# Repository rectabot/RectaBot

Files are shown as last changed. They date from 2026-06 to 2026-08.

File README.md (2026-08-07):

# RectaBot — 5-Axis CNC Controller

Open-source 5-axis CNC controller based on the Raspberry Pi RP2350B microcontroller running grblHAL firmware. Designed for hobby and workshop applications.

🌐 **[rectabot.org](https://rectabot.org)** — product, documentation and firmware configurator.

_RectaBot is the first piece of an open CNC ecosystem we're actively building. New parts are shared here as they're finished and verified — no roadmaps, no dates, just working hardware and software._

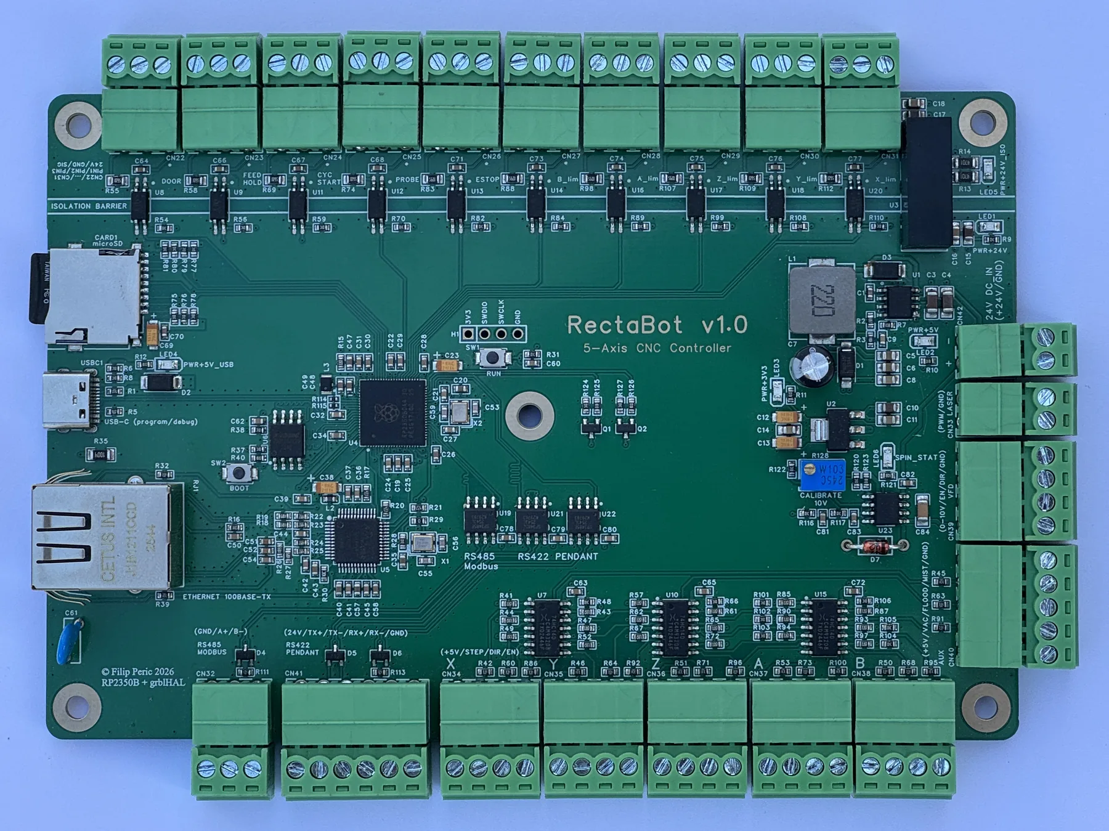
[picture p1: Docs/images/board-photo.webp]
RectaBot v1.0 — assembled board


---

## 📊 Project Status

| | |
|---|---|
| **Current version** | v1.0 |
| **Status** | ✅ v1.0 — running a machine: homing, probing, Modbus spindle, Ethernet, SD. One interface is hardware only — the RS-422 pendant header, which the firmware does not use |
| **First production batch** | 5 boards (JLCPCB Economic PCBA + ENIG finish) |
| **Firmware** | grblHAL fork for RP2350B |
| **Software** | [RectaControl](https://github.com/rectabot/RectaControl) — desktop sender built for this board |
| **Form factor** | 150 × 100 mm, 4-layer PCB, 1.6mm |

---

## 🎯 What is RectaBot?

A 5-axis CNC controller with optical input isolation, integrated Ethernet, and a VFD interface.

### Key features

- 🧩 **Single-board, fully integrated** — no add-on driver boards, breakout modules, or level-shifter add-ons to wire up. Every active part is soldered down (only the field-wiring terminals plug in), so vibration can't work a module loose over time; high-speed step/dir and comms lines are laid out for EMI immunity. Stepper drivers stay external — this board commands DM556-class drivers rather than replacing them — and coolant needs 2–3 relays on `CN40` — an optocoupler-input module or a solid-state relay, both wired and run ([which ones](Docs/Assembly/Quick_Start_Guide.md#which-relay-to-buy))
- ⚙️ **5-axis stepper control** (X, Y, Z, A, B) — PIO-based step generation up to **300kHz per axis**
- 🔌 **Spindle 0-10V interface** with overvoltage protection — compatible with Huanyang/Lapond/Delta/Hitachi VFDs
- 🛡️ **Optically isolated inputs** — all 10 field inputs through LTV-217-B-G optocouplers on a dedicated 24V_ISO rail (input side only)
- 🌐 **On-board Ethernet 10/100 Mbps** — a **discrete W5500** PHY laid out to WIZnet's reference design and their engineers' recommendations (not a plug-on module), with J1B1211CCD integrated magnetics + Bob Smith termination and controlled 100Ω differential pairs
- 💾 **MicroSD slot** for G-code files and configuration
- 🔋 **24V DC power input** (buck-regulated to 5V) — **ORing Schottky diodes** let the 24V supply and USB-C stay connected **at the same time** and hand off the 5V rail automatically; **no VBUS/5V select jumpers** to flip by hand (also blocks USB-C back-feed)
- 📡 **RS-485 Modbus + RS-422 Pendant** interfaces
- 🚦 **10 isolated inputs** + **3 auxiliary 5 V outputs** (Mist M7 / Flood M8 / Vac M62) — 330 Ω series, 25 mA per pin; drives relay modules and solid-state relays alike

**Detailed specification:** [Docs/Reference/Product_Specification_v1.0.md](Docs/Reference/Product_Specification_v1.0.md)

---

## 📂 Repository structure

```
RectaBot/
├── Docs/                                # 📚 All documentation (read first!)
│   ├── Assembly/                        # Build & first power-on
│   │   ├── Quick_Start_Guide.md         # From unboxing to first motor (2-3h)
│   │   ├── First_Power_On_Procedure.md  # Safe first power-on with a multimeter
│   │   └── Hand_Solder_Components.md     # 28 TH components for hand-soldering
│   ├── Reference/                       # Electrical & design reference
│   │   ├── Product_Specification_v1.0.md # Complete datasheet/spec
│   │   ├── Pinout.md                    # RP2350B pinmap (GP0-GP47)
│   │   ├── Schematic_References.md       # Reference schematics for all ICs
│   │   ├── Hardware_Design_Guidelines.md # PCB layout guidelines
│   │   ├── VFD_Wiring_Guide.md          # VFD connection guide (analog 0-10V)
│   │   └── VFD_Modbus_Setup.md          # VFD spindle control over RS-485/Modbus
│   ├── Manufacturing/                   # Send-to-fab production data
│   │   ├── BOM_v1.0_final.csv           # Bill of Materials (~80 components)
│   │   ├── CPL_RectaBot_V1.0.csv        # Component Placement List for JLCPCB
│   │   ├── LCSC_Additional_Order.csv    # TH parts for a separate LCSC order
│   │   └── Gerber_RectaBot_1.0/         # Production-ready Gerber files
│   └── Brand_Assets/                    # Logo files (SVG) — brand reserved, not open-licensed
├── website/                             # rectabot.org — landing page, deployed by Actions
│   └── configurator/                    # Firmware picker: machine layout → the matching .uf2
│
└── (Submodules live in separate repos — see below)
```

## 🔗 Related repositories

RectaBot is split across separate GitHub repos for better modularity:

| Repo | Contents |
|---|---|
| **[rectabot/RectaBot](https://github.com/rectabot/RectaBot)** (this one) | Hardware design (Gerber), docs, BOM, brand assets, configurator tool |
| **[rectabot/RectaBot-firmware](https://github.com/rectabot/RectaBot-firmware)** | grblHAL fork with RectaBot board map + pre-built UF2 |
| **[rectabot/RectaControl](https://github.com/rectabot/RectaControl)** | Desktop sender (Electron) — settings, probing, 3D toolpath, firmware flashing |

**Clone everything at once:**
```powershell
git clone https://github.com/rectabot/RectaBot.git
git clone https://github.com/rectabot/RectaBot-firmware.git
git clone https://github.com/rectabot/RectaControl.git
```

---

## 🔧 Hardware

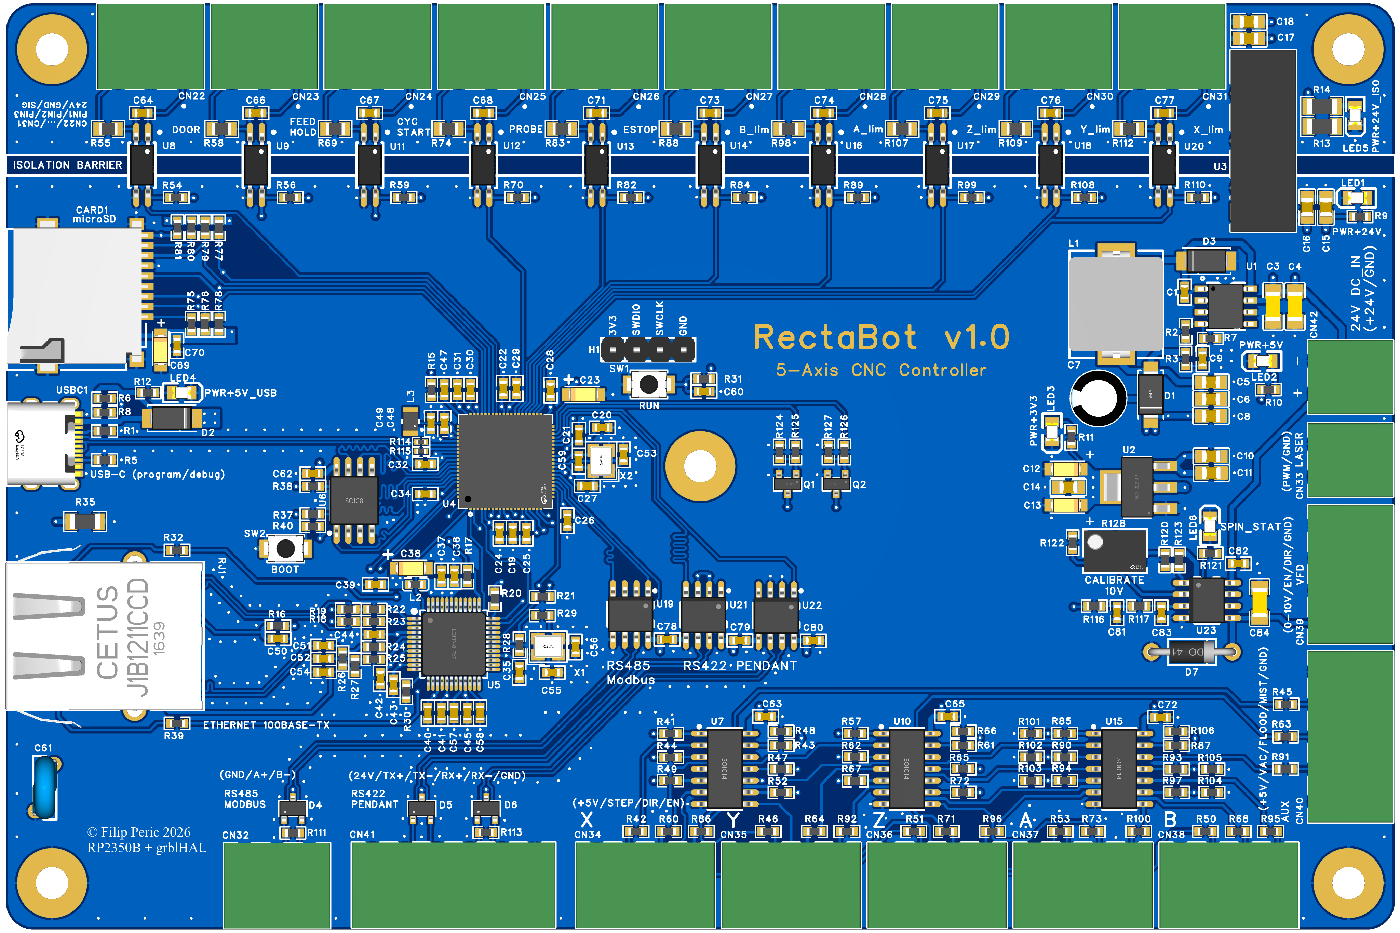
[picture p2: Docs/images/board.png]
RectaBot v1.0 — board layout with silkscreen labels


### Core components

| Component | Role |
|---|---|
| **Raspberry Pi RP2350B** (QFN-80) | Dual ARM Cortex-M33 @ 150MHz, 48 GPIO, 12 PIO state machines |
| **WIZnet W5500** | Hardware TCP/IP stack, 10/100 Ethernet |
| **74HC14D ×3** | Schmitt-trigger inverters for 3.3V→5V level shift (all step/dir/en signals) |
| **LTV-217-B-G ×10** | Optocouplers for all input signals (limit switches, ESTOP, probe, controls) |
| **LM358DR2G** | Op-amp for PWM→0-10V spindle interface |
| **2N7002 ×2** | Open-drain MOSFETs for VFD EN/DIR signals |
| **SP3485EN-L/TR ×3** | 3.3V native RS-485/RS-422 transceivers (1 Modbus + 2 Pendant) |
| **B2424S-2WR3** | Isolated 24V→24V DC/DC for opto LED supply |

### Power Tree

```
24V DC IN ──┬──► TPS5430 buck ──► +5V (3A)
            │                                 │
            ├──► B2424S-2WR3 isolation ──► +24V_ISO (opto LEDs)
            │
            └──► LM358 (op-amp supply, 24V rail-to-rail)

+5V ──► AMS1117-3.3 LDO ──► +3.3V (MCU, W5500, SP3485)
```

### System Block Diagram

```
                       ┌─────────────────────────────────────┐
                       │     RectaBot v1.0 — RP2350B MCU     │
                       │   (Dual Cortex-M33 @ 150MHz)        │
                       └─────────────────────────────────────┘
                                       │
       ┌───────────────────────┬───────┴───────┬───────────────────────┐
       │                       │               │                       │
       ▼                       ▼               ▼                       ▼
┌──────────────┐        ┌──────────────┐ ┌──────────────┐       ┌──────────────┐
│  MOTION      │        │  SPINDLE     │ │  AUX (RELAY) │       │  I/O & COMM  │
│              │        │              │ │              │       │              │
│ PIO step gen │        │ PWM @ 25kHz  │ │ GP0-2 →      │       │ SPI0 W5500   │
│ GP8-22 →     │        │ GP27 →       │ │ 74HC14D      │       │ UART1 RS485  │
│ 74HC14D ×3   │        │ LM358 op-amp │ │ Mist/Flood/  │       │ UART0 RS422  │
│ (Schmitt inv)│        │ + 2N7002 ×2  │ │ Vacuum       │       │ SPI1 microSD │
└──────┬───────┘        └──────┬───────┘ └──────┬───────┘       └──────┬───────┘
       │                       │                │                      │
       ▼                       ▼                ▼                      ▼
┌──────────────┐        ┌──────────────┐ ┌──────────────┐       ┌──────────────┐
│ CN34-CN38    │        │ CN39 (VFD)   │ │ CN40 (AUX)   │       │ RJ45 + USB-C │
│ 5× Stepper   │        │ 0-10V analog │ │ Mist/Flood/  │       │ + CN32 RS485 │
│ STEP/DIR/EN  │        │ EN/DIR open- │ │ Vacuum +     │       │ + CN41 RS422 │
│ (5V CMOS)    │        │ drain MOSFET │ │ 5V/VAC/GND   │       │ + microSD    │
└──────────────┘        └──────────────┘ └──────────────┘       └──────────────┘

     ─ ─ ─ ─ ─ ─ ─ ─ ─ ─ ─ INPUT-SIDE ISOLATION (10× OPTO) ─ ─ ─ ─ ─ ─ ─ ─ ─ ─ ─

                              ┌─────────────────────┐
                              │  10× ISOLATED       │
                              │  INPUTS             │
                              │                     │
                              │ LTV-217-B-G opto    │
                              │ + 24V_ISO domain    │
                              │ (B2424S-2WR3 DC/DC) │
                              │                     │
                              │ Limits, ESTOP,      │
                              │ Probe, Controls     │
                              │                     │
                              │ → CN22-CN31         │
                              └─────────────────────┘

Note: v1 isolates the input side only.
```

---

## 🚀 Quick Start

> **📦 Status:** The first batch of five v1.0 boards has been assembled, and a board has been driving a machine since: homing and hard limits, probing cycles, a Modbus VFD spindle, Ethernet, the SD card and the coolant outputs. Everything documented below is verified on hardware, with one exception — nothing has yet been connected to the **RS-422 pendant header (CN41)**. Its transceivers are populated and its pins are documented, but the link has never carried traffic, so treat that one interface as untested. Follow the assembly and wiring guides below.

**Main guides:**
- **[Quick_Start_Guide.md](Docs/Assembly/Quick_Start_Guide.md)** — Complete walkthrough from unboxing to first motor (estimated: 2-3h)
- **[First_Power_On_Procedure.md](Docs/Assembly/First_Power_On_Procedure.md)** — Safety procedure for the first power-on with a multimeter

**Main steps (summary):**
1. Visual inspection of the board (10 min)
2. Hand-soldering 28 TH components ([list](Docs/Assembly/Hand_Solder_Components.md), 60-90 min)
3. Pre-Power-On continuity tests (15 min)
4. First Power-On + LED + voltage verification (10 min)
5. Firmware flash via BOOTSEL+USB (15 min) — [the configurator](https://rectabot.org/configurator/) names the `.uf2` your motor layout needs
6. grblHAL configuration (`$$` parameters for RectaBot, 20 min) — RectaControl's Settings panel, with a steps/mm calculator
7. First axis test with a DM556 driver (10 min)
8. VFD wiring — [analog 0-10V](Docs/Reference/VFD_Wiring_Guide.md) or [RS-485/Modbus](Docs/Reference/VFD_Modbus_Setup.md)

---

## 🤝 Acknowledgments

- **[grblHAL](https://github.com/grblHAL)** community — for the incredible open-source firmware
- **Raspberry Pi Foundation** — for the RP2350 chip and accessible pricing
- **JLCPCB & LCSC** — for accessible prototype manufacturing
- **EasyEDA** — for the CAD tool that made this project possible for a solo developer

---

## 📜 License

- **Code, documentation:** MIT (see [LICENSE](LICENSE))
- **Hardware design files** (Gerber, BOM, CPL): CERN-OHL-S v2 (see [LICENSE.hardware](LICENSE.hardware))
- **Brand assets** (the name "RectaBot" + logo SVGs): **reserved — all rights reserved**, not open-licensed (see [Docs/Brand_Assets/README.md](Docs/Brand_Assets/README.md))
- **grblHAL firmware fork:** GPL-3.0 (inherits from upstream, in the separate [RectaBot-firmware](https://github.com/rectabot/RectaBot-firmware) repo)
- **RectaControl sender:** GPL-3.0 (separate [RectaControl](https://github.com/rectabot/RectaControl) repo)

---

## 📬 Contact

**Project lead:** Filip Perić
**Website:** [rectabot.org](https://rectabot.org)
**Email:** hello@rectabot.org
**Location:** Serbia

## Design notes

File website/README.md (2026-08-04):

# rectabot.org — RectaBot website

Static landing page + grblHAL firmware configurator for RectaBot. Part of the
`rectabot/RectaBot` repo; deployed to GitHub Pages (custom domain **rectabot.org**)
from this `website/` folder via `.github/workflows/deploy-pages.yml`.

- `index.html` — landing page (zero build; Tailwind + fonts via CDN)
- `configurator/` — firmware selector; the only copy. Its `VARIANTS` map and the
  firmware repo's `variants/` folders share the same keys, so a new build means
  adding it in both places
- `board-photo.webp` / `board-photo-full.webp` — board photo (thumbnail + lightbox)
- `rectacontrol.png` — sender screenshot; copied from the RectaControl repo's
  `docs/images/rectacontrol.png`, re-copy it when the UI changes
- `Brand_Assets/favicon.svg`, `favicon.svg` — browser tab icon (identical files)
- `apple-touch-icon.png` — 180×180, for iOS home screens, which ignore SVG icons.
  Resized from the RectaControl app icon (`rectacontrol/build/icon.png`), so the
  two stay the same picture; regenerate from there if the brand mark changes
- `CNAME` — custom domain (rectabot.org)

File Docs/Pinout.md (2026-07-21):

# RP2350B Pinmap (RectaBot v1.0)

The RP2350B (QFN-80) has 48 GPIO pins (GP0-GP47).

**Level shift 3.3V → 5V:** Stepper signals (STEP/DIR/EN) and coolant outputs (VAC/FLOOD/MIST) pass through the **74HC14D** (Schmitt-trigger HEX inverter, Basic part on JLCPCB). Three 74HC14D chips (U7, U10, U15) cover 18 signals.

**The 74HC14D inverts the signal, but in Common Anode mode this is already accounted for** — no firmware STEP invert is needed. Validated on bench (TB6600 + NEMA17, smooth both directions, no missed steps up to F2000):
- `$2=0` — STEP_INVERT_MASK. With `$2=0` the 74HC14D output idles HIGH (OPT− high → opto OFF) and each step pulse briefly pulls OPT− low (opto ON) — correct for Common Anode. Setting `$2`≠0 would hold the input opto continuously ON at idle and likely cause missed steps at speed.
- `$3=0` — DIRECTION_INVERT_MASK baseline. Set per-axis on the actual machine so X+/Y+/Z+ move in the correct direction.
- `$4` — STEPPER_ENABLE_INVERT_MASK: **not yet validated** (ENA left unconnected during bench test, driver always enabled). Verify once ENA is wired to the drivers.
- Coolant invert via driver configuration

Stepper drivers operate in **Common Anode** mode: +5V on OPT+, the 74HC14D pulls OPT− to GND. Validated with TB6600; verified-under-load values (and any driver-specific differences, e.g. DM-series) to be confirmed when machining.

**Input galvanic isolation:** 10 isolated inputs via **LTV-217-B-G** optocouplers (U8-U20), powered from **+24V_ISO** (B2424S-2WR3 isolated DC/DC). GND_ISO is separated from GND by a 2mm copper void barrier.

**Input wiring (each connector: `24V · GND · SIG`):** the inputs are **sinking (active LOW)** — same convention as the VFD outputs.
- **Mechanical switch** (limit / E-stop, NO contact): wire between **GND** and **SIG**. The 24V pin is not needed.
- **Inductive sensor — NPN (sinking), recommended** (e.g. LJ12A3): use all three pins — **24V** (power) + **GND** + **SIG**. The sensor pulls SIG to GND when triggered.
- **PNP (sourcing) sensors are not directly compatible** (they drive SIG to 24V) — use an external relay module, as with PNP VFDs.

See the [hardware configurator](configurator/index.html) (Limit input type: NPN vs Mechanical) for the matching grblHAL `$` settings.

| Function | RP2350 Pin | Notes |
| :--- | :--- | :--- |
| **Auxiliary outputs** | | Through 74HC14D FREE channels → SSR |
| VAC | `GP0` | Through 74HC14D (inverted) → SSR, grblHAL M62/M63 |
| FLOOD | `GP1` | Through 74HC14D (inverted) → SSR, grblHAL M8/M9 |
| MIST | `GP2` | Through 74HC14D (inverted) → SSR, grblHAL M7/M9 |
| SD Card Detect | `GP3` | MicroSD socket CD switch (active LOW when card inserted) |
| **W5500 Ethernet (SPI0)** | | |
| MISO | `GP4` | SPI0 RX |
| SCSn | `GP5` | SPI0 CS |
| SCLK | `GP6` | SPI0 SCK |
| MOSI | `GP7` | SPI0 TX |
| **X axis** | | Through 74HC14D |
| STEP_X → STEP_X_5V | `GP8` | 74HC14D input/output |
| DIR_X → DIR_X_5V | `GP13` | 74HC14D input/output |
| EN_X → EN_X_5V | `GP18` | 74HC14D input/output |
| **Y axis** | | Through 74HC14D |
| STEP_Y → STEP_Y_5V | `GP9` | 74HC14D input/output |
| DIR_Y → DIR_Y_5V | `GP14` | 74HC14D input/output |
| EN_Y → EN_Y_5V | `GP19` | 74HC14D input/output |
| **Z axis** | | Through 74HC14D |
| STEP_Z → STEP_Z_5V | `GP10` | 74HC14D input/output |
| DIR_Z → DIR_Z_5V | `GP15` | 74HC14D input/output |
| EN_Z → EN_Z_5V | `GP20` | 74HC14D input/output |
| **A axis** | | Through 74HC14D |
| STEP_A → STEP_A_5V | `GP11` | 74HC14D input/output |
| DIR_A → DIR_A_5V | `GP16` | 74HC14D input/output |
| EN_A → EN_A_5V | `GP21` | 74HC14D input/output |
| **B axis (Y2 tandem)** | | Through 74HC14D |
| STEP_B → STEP_B_5V | `GP12` | 74HC14D input/output |
| DIR_B → DIR_B_5V | `GP17` | 74HC14D input/output |
| EN_B → EN_B_5V | `GP22` | 74HC14D input/output |
| **W5500 Ethernet** | | |
| W5500_INT (INTn) | `GP23` | Interrupt |
| **RS485 Modbus** | UART1 | MAX485 or external module |
| RS485 TX | `GP24` | UART1 TX → MAX485 DI |
| RS485 RX | `GP25` | UART1 RX ← MAX485 RO |
| RS485 DE/RE | `GP26` | Direction control |
| **Spindle / Laser** | | |
| Spindle PWM / Laser PWM | `GP27` | PWM for VFD and laser diode module (3.3V TTL, shared with CN39 + CN33). For VFD it goes through the LM358 0-10V converter; for laser, directly to CN33. |
| RS422 TX (Pendant) | `GP28` | UART0 TX → SP3485 Chip1 (TX hardwired) |
| RS422 RX (Pendant) | `GP29` | UART0 RX ← SP3485 Chip2 (RX hardwired) |
| Spindle Enable (VFD_EN) | `GP30` | Enable VFD → 2N7002 open-drain Q1 → CN39 pin 2 (VFD_EN, active LOW open-drain) |
| Spindle Dir (VFD_DIR) | `GP31` | Direction VFD → 2N7002 open-drain Q2 → CN39 pin 3 (VFD_DIR, active LOW open-drain) |
| W5500_RST (RSTn) | `GP32` | W5500 reset, 4.7kΩ pull-up |
| **Limits / Control inputs** | | Via LTV-217-B-G opto, 24V_ISO |
| X_MIN | `GP33` | X-axis limit switch |
| Y_MIN | `GP34` | Y-axis limit switch |
| Z_MAX | `GP35` | Z-axis limit switch (homing up) |
| A_MIN | `GP36` | A-axis limit switch |
| B_MIN | `GP37` | B-axis limit switch (Y2 auto-square) |
| ESTOP | `GP38` | Emergency Stop → grblHAL alarm |
| PROBE | `GP39` | Tool length probe |
| CYCLE_START | `GP40` | Cycle start |
| FEED_HOLD | `GP41` | Pause |
| DOOR | `GP42` | Safety door input (grblHAL `SAFETY_DOOR`): opening the door holds the machine until closed. Neutral default (no forced invert) — set `$14` DOOR bit to match the switch (NO/NC). |
| **SD card (SPI1)** | | |
| SD MOSI | `GP43` | SPI1 TX |
| SD MISO | `GP44` | SPI1 RX |
| SD CS | `GP45` | SPI1 CSN |
| SD CLK | `GP46` | SPI1 SCK |
| VBUS_DET | `GP47` | USB VBUS detect, 10kΩ/10kΩ divider (R6/R8) → 2.5V (above VIH=2.15V) |

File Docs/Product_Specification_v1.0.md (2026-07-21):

# RectaBot v1.0 — Product Specification

**Industrial-grade 5-axis CNC controller with integrated network, USB, isolated I/O, and spindle 0-10V interface.**

---

## 📑 Table of Contents

- [Product Overview](#-product-overview)
- [Key Features](#-key-features)
  - [Motion Control](#motion-control)
  - [Spindle Control](#spindle-control-new-in-v10)
  - [Isolated I/O](#isolated-io)
  - [Connectivity](#connectivity)
  - [Power Distribution](#power-distribution)
  - [Safety & EMI](#safety--emi)
- [Connector Pinout](#-connector-pinout)
  - [Power & USB](#power--usb)
  - [Stepper Motors](#stepper-motors-x-y-z-a-b)
  - [Spindle / Laser](#spindle--laser)
  - [Isolated Inputs](#isolated-inputs-24v_iso-domain)
  - [Auxiliary / Communication](#auxiliary--communication)
- [Electrical Specifications](#-electrical-specifications)
  - [Power](#power)
  - [Stepper Outputs](#stepper-outputs-per-axis)
  - [Spindle 0-10V Output](#spindle-0-10v-output)
  - [Spindle EN/DIR Outputs](#spindle-endir-outputs)
  - [Isolated Inputs](#isolated-inputs)
  - [Communication](#communication)
- [Compliance & Reliability](#-compliance--reliability)
- [Compatibility](#-compatibility)
  - [Stepper Drivers](#stepper-drivers)
  - [VFD Compatibility](#vfd-variable-frequency-drives)
  - [Laser Modules](#laser-modules)
  - [CNC Machines](#cnc-machines)
- [Onboard Components Summary](#-onboard-components-summary)
- [Mechanical](#-mechanical)
- [Firmware](#-firmware)
- [In the Box](#-in-the-box)
- [Documentation](#-documentation)
- [Support](#-support)
- [Legal](#-legal)
- [Revision History](#-revision-history)

---

## 📦 Product Overview

RectaBot is a professional CNC mill controller designed for hobby-pro and small workshop applications. Built around the powerful **Raspberry Pi RP2350B** microcontroller running open-source **grblHAL** firmware, it combines industrial-grade isolation, multi-axis stepper control, and modern connectivity in a single 150×100mm PCB.

| Property | Value |
|---|---|
| **Model** | RectaBot v1.0 |
| **Form factor** | 150×100mm 4-layer PCB |
| **MCU** | Raspberry Pi RP2350B (QFN-80, dual ARM Cortex-M33 @ 150MHz) |
| **Firmware** | grblHAL (open-source) |
| **Power input** | 24V DC, 2A max |
| **Operating temperature** | -10°C to +60°C |
| **PCB layers** | 4 (top signal, GND plane, power plane, bottom signal) |
| **Input isolation** | Optical isolation on all 10 field inputs (LTV-217-B-G, 5kV rated, 24V_ISO domain). Outputs share MCU ground in v1. |

---

## 🎯 Key Features

### Motion Control
- ✅ **5-axis stepper control** (X, Y, Z, A, B) via PIO-based step generation
- ✅ **Common Anode** drive topology for DM556 / TB6600 / DM860 driver compatibility
- ✅ **5V logic-level** STEP/DIR/EN signals (via 74HC14D Schmitt trigger buffer)
- ✅ Hardware-accelerated step pulses up to **300kHz per axis**
- ✅ Y-axis auto-squaring (B-axis as ganged Y2)

### Spindle Control (NEW in v1.0)
- ✅ **0-10V analog speed output** for VFD compatibility (LM358 op-amp with trim calibration)
- ✅ **Open-drain Enable & Direction signals** (2N7002 MOSFET, 60V tolerant)
- ✅ **Overvoltage protection** (12V Zener clamp on 0-10V output)
- ✅ Compatible with **Huanyang, Lapond, Delta, ATO, Hitachi** VFDs out-of-the-box
- ✅ PWM range: 0-25kHz, supports laser modulation on shared output
- ✅ Visual brightness LED indicator follows actual VFD output

### Isolated I/O
- ✅ **10 optically isolated inputs** (24V_ISO domain, LTV-217 optocouplers, 5kV component rating)
  - 5× limit switches (X_MIN, Y_MIN, Z_MAX, A_MIN, B_MIN)
  - E-Stop, Probe, Cycle Start, Feed Hold, Door safety
- ✅ **3 SSR-compatible outputs** (Mist M7, Flood M8, Vacuum M62/M63)
- ✅ **24V_ISO isolated supply** (B2424S-2WR3, 2W isolated DC-DC)
- ✅ Hardware debounce (100nF parallel to optocoupler LED)

### Connectivity
- ✅ **Ethernet 10/100 Mbps** via W5500 + RJ45 with integrated magnetics
  - Bob Smith termination for EMI suppression
  - 100Ω diff impedance controlled TX/RX pairs
- ✅ **USB-C 2.0 Full-Speed** for programming, debugging, host control
  - VBUS detection on GP47
  - CC1/CC2 5.1kΩ pull-down (device mode)
  - 22Ω series termination on D+/D-
- ✅ **RS-485 Modbus** for VFD spindle and external I/O expansion (SP3485)
- ✅ **RS-422 Pendant interface** for RectaPad (full duplex, dual SP3485)
- ✅ **MicroSD card** for G-code file storage and configuration

### Power Distribution
- ✅ **24V → 5V buck converter** (TPS5430DDAR, 3A capability)
- ✅ **5V → 3.3V LDO** (AMS1117-3.3, 800mA)
- ✅ **24V_ISO isolated rail** (83mA for opto LED inputs)
- ✅ **5 power LED indicators** (24V, 5V, 3V3, USB, ISO status)
- ✅ **+5V ORing diode** (SS54) — buck 5V and USB-C 5V coexist without back-feed

### Safety & EMI
- ✅ **4-layer stackup** with solid GND plane (L2) for return paths
- ✅ **PSM712 TVS arrays** on RS-485/422 + Bob Smith on RJ45/USB-C shells
- ✅ **Input-side isolation barrier** (2mm copper void) — separates MCU ground from 24V_ISO input domain. Stepper/Spindle/AUX outputs share MCU ground in v1 (full I/O isolation planned for v2).
- ✅ **Failsafe spindle defaults** during MCU reset (open-drain MOSFETs OFF by default)
- ✅ **12V Zener clamp** on spindle 0-10V output (protects VFD from MCU failure)

---

## 🔌 Connector Pinout

### Power & USB
| Connector | Type | Function |
|---|---|---|
| **CN42** | 2-pin screw (3.5mm) | 24V DC input |
| **USBC1** | USB-C | Programming, debug, host control |
| **RJ1** | RJ45 | Ethernet 10/100 Mbps |

### Stepper Motors (X, Y, Z, A, B)
| Connector | Pinout | Function |
|---|---|---|
| **CN34** | X axis (4-pin) | STEP, DIR, EN, GND (5V Common Anode) |
| **CN35** | Y axis (4-pin) | STEP, DIR, EN, GND |
| **CN36** | Z axis (4-pin) | STEP, DIR, EN, GND |
| **CN37** | A axis (4-pin) | STEP, DIR, EN, GND |
| **CN38** | B axis (4-pin) | STEP, DIR, EN, GND (Y2 tandem) |

### Spindle / Laser
| Connector | Pinout | Function |
|---|---|---|
| **CN39** | 4-pin (3.5mm) | VFD_10V, VFD_EN, VFD_DIR, GND |
| **CN33** | 2-pin (3.5mm) | Laser PWM, GND |

### Isolated Inputs (24V_ISO domain)
| Connector | Function |
|---|---|
| **CN22** | DOOR (NC chain of MAX limit switches) |
| **CN23** | FEED HOLD |
| **CN24** | CYCLE START |
| **CN25** | PROBE |
| **CN26** | E-STOP |
| **CN27** | B_LIMIT |
| **CN28** | A_LIMIT |
| **CN29** | Z_LIMIT |
| **CN30** | Y_LIMIT |
| **CN31** | X_LIMIT |

### Auxiliary / Communication
| Connector | Function |
|---|---|
| **CN40** | AUX (+5V, VAC, FLOOD, MIST, GND) — 5-pin SSR outputs |
| **CN41** | Programming / debug (6-pin) |
| **CN32** | RS-485 Modbus (GND/A+/B-) |
| **CARD1** | MicroSD socket (SPI mode) |

---

## ⚙️ Electrical Specifications

### Power
| Parameter | Min | Typ | Max | Unit |
|---|---|---|---|---|
| Input voltage | 12 | 24 | 30 | V DC |
| Input current (no load) | — | 150 | 250 | mA |
| Input current (typical) | — | 400 | 800 | mA |
| Input current (worst case all outputs active) | — | — | 2000 | mA |
| 5V rail output | 4.9 | 5.0 | 5.1 | V |
| 3.3V rail output | 3.25 | 3.30 | 3.35 | V |
| 24V_ISO rail output | 23 | 24 | 25 | V |
| 24V_ISO max current | — | — | 83 | mA |

### Stepper Outputs (per axis)
| Parameter | Value |
|---|---|
| Logic level (after 74HC14D) | 5V CMOS |
| Output drive current | ±25mA peak per pin |
| STEP pulse minimum width | 1µs |
| STEP frequency max | 300kHz |
| DIR setup time | 5µs (configurable) |

### Spindle 0-10V Output
| Parameter | Value |
|---|---|
| Output voltage range | 0 - 10V DC |
| Output linearity | ±0.5% (after trim calibration) |
| Output impedance | ~1kΩ (series limit + Zener) |
| Output ripple at 25kHz PWM | <5mV |
| Trim adjustment range | Gain 1.5x to 3.0x |
| Overvoltage clamp | 12V (1N4742A Zener) |
| Settling time (0→10V) | <20ms |

### Spindle EN/DIR Outputs
| Parameter | Value |
|---|---|
| Output type | Open-drain (N-MOSFET) |
| Max sink current | 300mA |
| Max applied voltage | 60V DC |
| ON-state Vds | <100mV at 100mA |
| OFF-state leakage | <1µA |
| Failsafe default (MCU reset) | OFF (high-Z) via pull-down |

### Isolated Inputs
| Parameter | Value |
|---|---|
| Input voltage range | 12-30V DC (24V nominal) |
| Input current | ~5mA at 24V |
| Isolation rating | 5kV (LTV-217) |
| Response time (with debounce cap) | <1ms |
| Logic threshold | Optocoupler current ~3mA |

### Communication
| Interface | Speed | Distance | Notes |
|---|---|---|---|
| Ethernet | 100Mbps | 100m | RJ45 with integrated magnetics |
| USB-C | 12Mbps (Full-Speed) | 3m | Device mode, CDC + UF2 |
| RS-485 Modbus | up to 1Mbps | 1200m | Half-duplex, 120Ω termination |
| RS-422 Pendant | up to 1Mbps | 100m | Full-duplex differential |
| SPI (microSD) | 25MHz | <30mm | Mode 0, on-board |

---

## 🛡️ Compliance & Reliability

### EMI/EMC Design
- 4-layer PCB with solid GND plane for low-impedance return paths
- Edge stitching vias every 5mm (Faraday cage effect)
- Diff pair impedance control (USB 90Ω, Ethernet 100Ω, RS-422/485 100Ω)
- TVS protection on all external connectors (RS-485, RS-422, USB shell, Ethernet shell)
- Bob Smith termination on Ethernet RJ45 + USB-C shells

### Protection Features
- ⚠️ Note: the 24V input has **no** reverse-polarity protection in v1 (planned for v2)
- ESD protection on USB data lines (22Ω series + Bob Smith chassis coupling)
- TVS arrays on RS-485/422 lines (PSM712-LF)
- Optical isolation on all field inputs (LTV-217-B-G, 5kV component rating); outputs share MCU ground in v1
- Spindle output overvoltage clamp (12V Zener)
- Open-drain MOSFET protection for EN/DIR (60V tolerance)
- Failsafe spindle OFF during MCU reset/boot

### Quality Standards
- **CE/RoHS compliant** components (Pb-free, halogen-free where available)
- **Industrial-grade** electrolytics and ceramics (X7R dielectric)
- **Operating range:** -10°C to +60°C (component-limited)
- **Storage range:** -25°C to +85°C

---

## 🧰 Compatibility

### Stepper Drivers
- ✅ Leadshine **DM556** (most common)
- ✅ Leadshine **DM860**
- ✅ MakerBase **TB6600**
- ✅ DQ542MA, DQ860MA
- ✅ Any Common Anode optocoupler driver (5V signal)

### VFD (Variable Frequency Drives)
- ✅ **Huanyang** HY01/HY02 (most common, 0-10V + RUN/DIR)
- ✅ **Lapond** SVD-EM series
- ✅ **Delta** VFD-M, VFD-EL
- ✅ **ATO** generic VFDs
- ✅ **Hitachi** WJ200
- ⚠️ **Siemens G120, ABB ACS580** (industrial PNP): requires external relay module
- ✅ Modbus RS-485 spindle control (any VFD with Modbus support)

### Laser Modules
- ✅ Diode laser modules with TTL PWM input (Sculpfun, Atomstack, NEJE)
- ✅ Up to 25kHz PWM modulation rate
- ✅ 3.3V TTL signal level

### CNC Machines
- ✅ Router-style mills (drewno, MDF, aluminijum)
- ✅ Plasma cutters (with appropriate driver interface)
- ✅ Engraving machines
- ✅ XY plotters and pen-plotters
- ⚠️ Large industrial machines: confirm motor driver compatibility

---

## 🔬 Onboard Components Summary

### Critical IC's
| Designator | Part | Function |
|---|---|---|
| U1 | TPS5430DDAR | 24V→5V buck converter (3A) |
| U2 | AMS1117-3.3 | 5V→3.3V LDO (800mA) |
| U3 | B2424S-2WR3 | Isolated 24V DC/DC for I/O domain |
| U4 | RP2350B | Main MCU (dual M33 @ 150MHz, 48 GPIO) |
| U5 | W5500 | Ethernet controller (SPI) |
| U6 | W25Q128JVSIQ | 128Mbit (16MB) QSPI flash |
| U7, U10, U15 | 74HC14D | Stepper level shifter (3.3V→5V) |
| U8-U20 | LTV-217-B-G | Isolated input optocouplers (×10) |
| U19, U21, U22 | SP3485EN-L/TR | RS-485/422 transceivers (×3) |
| U23 | LM358DR2G | 0-10V spindle op-amp |
| Q1, Q2 | 2N7002 | Spindle EN/DIR open-drain buffers |
| RJ1 | J1B1211CCD | Integrated RJ45 + magnetics (WIZnet) |

### Protection & Filtering
- 3× PSM712-LF-T7 TVS arrays (RS-485, RS-422)
- 1× 1N4742A Zener (spindle output clamp)
- 1× SS54 Schottky (+5V ORing)
- 2× SS34 Schottky (buck output)
- 1× 1nF/2kV ceramic (Bob Smith chassis coupling)
- 2× crystal oscillators (12MHz MCU, 25MHz Ethernet)

---

## 📐 Mechanical

| Property | Value |
|---|---|
| PCB dimensions | 150 × 100 mm |
| PCB thickness | 1.6 mm |
| Copper weight | 1oz outer / 0.5oz inner |
| Surface finish | HASL (lead-free) or ENIG |
| Solder mask | Green (default), other colors available |
| Silkscreen | White, with component reference designators |
| Mounting holes | 4× M3 (3.2mm drill) at corners |
| Mounting hole keepout | 6mm clearance |
| Connector spacing | All field connectors on board edges |

### Connector Specifications
- **Screw terminals:** KEFA KF2EDGR 3.5mm pitch (3/4/5/6 pin variants) — TH, soldered manually
- **Ethernet:** WIZnet J1B1211CCD RJ45 with shielded shell + integrated magnetics — TH, soldered manually
- **USB-C:** Korean Hanyong TYPE-C-31-M-12 (24-pin SMD with TH alignment posts) — **SMT, JLCPCB assembly**
- **MicroSD:** Push-push SMD socket — SMT, JLCPCB assembly

---

## 🔧 Firmware

### grblHAL Configuration
- **Board map:** `Firmware/boards/my_machine_map.h`
- **Steps:** configurable per axis via `$100-$104`
- **Max rate:** configurable per axis via `$110-$114`
- **Acceleration:** configurable per axis via `$120-$124`
- **Max spindle RPM:** `$30` (default 24000)
- **Invert masks:** `$2=31`, `$3=31`, `$4=1` (for 74HC14D inversion)

### Supported G-code
- G0-G3 (rapid, linear, arc moves)
- G4 (dwell)
- G10 (coordinate system)
- G17-G19 (plane selection)
- G20/G21 (inch/mm)
- G28/G30 (home)
- G38.x (probe)
- G54-G59 (coordinate systems)
- G90/G91 (absolute/relative)
- G92 (set position)
- G93/G94 (inverse/units per min)
- M0-M2 (program flow)
- M3/M4/M5 (spindle on CW/CCW/off)
- M7/M8/M9 (mist, flood, coolant off)
- M30 (program end)
- M62/M63 (auxiliary output control)

### Real-time Commands
- `?` Status query (position, feed, spindle)
- `~` Cycle resume
- `!` Feed hold
- `Ctrl-X` Soft reset

### Communication Modes
- USB CDC (default, virtual serial)
- Ethernet TCP (Telnet on port 23, websocket on port 80)
- Ethernet UDP (broadcast for discovery)

---

## 📦 In the Box

- 1× RectaBot v1.0 PCB (assembled)
- Quick Start Guide
- Connector pinout reference card
- Link to online documentation

### Optional Accessories (separately sold)
- RectaPad (handheld controller with LCD + touch)
- Pre-made wiring harness for common VFDs
- Power supply 24V/5A
- Enclosure (DIN rail or panel mount)

---

## 📚 Documentation

- [Pinout Reference](Pinout.md)
- [Hardware Design Guidelines](Hardware_Design_Guidelines.md)
- [Schematic References](Schematic_References.md)
- [PCB Routing Rules](../PCB_ROUTING_RULES.md)
- [VFD Wiring Guide](VFD_Wiring_Guide.md)
- [Silkscreen Layout Guide](Silkscreen_Layout_Guide.md)
- [FEDEVEL Design Tips](../FEDEVEL_TIPS.md)

---

## 🆘 Support

- **GitHub:** github.com/rectabot (TBD)
- **Documentation:** docs.rectabot.com (TBD)
- **Community:** Discord "RectaBot Users" (TBD)
- **Email:** support@rectabot.com (TBD)

---

## ⚖️ Legal

- **License (Hardware):** CERN-OHL-S v2 (Strong reciprocal open hardware)
- **License (Firmware):** GPL v3 (grblHAL base)
- **Warranty:** 12 months limited (EU consumer rights)
- **CE marking:** Self-certified per EMC Directive 2014/30/EU (DoC available)
- **RoHS:** Compliant (lead-free components used where available)

---

## 📊 Revision History

| Version | Date | Changes |
|---|---|---|
| **v1.0** | 2026-05-28 | Initial production release with integrated 0-10V spindle interface, 2N7002 EN/DIR protection, Zener clamp |
| v0.9 | 2026-04-20 | Pre-production prototype (no 0-10V, no protection MOSFETs) |
| v0.5 | 2026-03-15 | Schematic complete, layout draft |
| v0.1 | 2026-02-01 | Concept phase |

---

*RectaBot is an open-source project designed and manufactured in Serbia by Filip Perić.*

*Document version 1.0 — last updated 2026-05-28.*

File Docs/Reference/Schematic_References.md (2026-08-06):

# Reference Schematics and Design Notes (RectaBot)

This document collects guidelines and reference schematics for the key IC components from our `BOM.csv`. We focus on maximizing the use of passive SMD components (mostly 0603 and 0805) from the JLCPCB "Basic" catalog, since they are essentially free to assemble.

## 1. Power rail (24V → 5V): TPS5430DDAR
**Datasheet:** [TI TPS5430DDAR](https://www.ti.com/lit/ds/symlink/tps5430.pdf)
The TPS5430 requires a few key passive components to operate as a stable "Buck" (step-down) converter.

**Reference connections:**
- **VIN (Pin 7)**: connects to 24V. Requires a ceramic cap to GND (C_in), typically `10uF / 50V` (0805).
- **EN (Pin 3)**: can be left open (floating) for automatic start, or connected to VIN through a 100k resistor.
- **PH (Pin 8)**: power switch output.
  - A **Schottky diode (e.g. SS34 or B340A)** runs from GND to PH (cathode on PH).
  - The **inductor (L1)** is 33 µH to 47 µH (must handle 3A+, CD75 package or larger).
- **BOOT (Pin 1)**: cap between BOOT and PH pins. Standard value: `10 nF / 50V` (0603).
- **VOUT (after inductor L1)**: requires output filtering, i.e. a `220 uF` (electrolytic) cap in parallel with a `10uF` ceramic.
- **VSENSE (Pin 4)**: feed the output voltage via a divider.
  - Formula: `Vout = 1.221V * (R1/R2 + 1)`.
  - For a 5.0V output: **R1 = 10 kΩ**, **R2 = 3.24 kΩ** (1% precision).

*BOM passives:* C_in and C_out components are easy to find in the JLCPCB Basic catalog. The 10k (0603) and 3.24k (0603 1%) resistors are also Basic.

## 2. LDO (5V → 3.3V): AMS1117-3.3
**Datasheet:** [AMS1117](http://www.advanced-monolithic.com/pdf/ds1117.pdf)
Trivial and ultra-cheap!
- **IN**: +5V (from the TPS5430). Requires a `10uF` cap to GND.
- **OUT**: +3.3V. Requires a `22uF` tantalum or `10uF` ceramic cap to GND for stability.
- **GND**: ground.

## 3. Axis buffers (3.3V → 5V): 74HC14D
RectaBot v1.0 uses the **74HC14D** (Schmitt-trigger HEX INVERTER) instead of the 74HCT245. Reasons: Basic on JLCPCB, the clean Schmitt input filters noise, smaller SOIC-14 package.

**Datasheet:** [74HC14D](https://assets.nexperia.com/documents/data-sheet/74HC_HCT14.pdf)
- **VCC (Pin 14)**: +5V (add a `100nF` decoupler very close to the chip).
- **GND (Pin 7)**: ground.
- **Inputs 1A, 2A, ..., 6A**: connected to MCU GP signals (3.3V TTL). The 74HC14D inputs accept 3.3V as logic 1 because the Schmitt threshold (VT+ ~3V at VCC=5V) can be crossed with 3.3V. **NOTE:** strictly speaking, the 74HC14D wants VIH≥3.5V at VCC=5V; in practice 3.3V works reliably, but for maximum safety the 74**HCT**14D (TTL-compatible, VIH=2V) can be used.
- **Outputs 1Y, 2Y, ..., 6Y**: INVERTED 5V output → goes to STEP-/DIR-/EN- pins of the DM556 (through a 330Ω series resistor). The DM556 common wire goes to the **+5V** rail (Common Anode topology).
- **Three 74HC14D chips** (U7, U10, U15) cover 18 signals: 5×STEP + 5×DIR + 5×EN + 3×coolant (MIST, FLOOD, VAC).
- **Firmware settings (validated on the reference board):** the 74HC14D inverts, but with Common Anode drivers the STEP pulse lands correctly with no invert. In grblHAL set:
  - `$2=0` — STEP invert OFF (Common Anode already accounts for the inversion; `$2`≠0 holds the opto on at idle → missed steps)
  - `$4=15` — ENABLE invert on all axes (7 = 3-axis, 15 = 4-axis, 31 = 5-axis)
  - `$5=0` — LIMIT invert OFF · `$6=1` — PROBE invert ON
  - `$3` — DIRECTION invert is **per-machine** (set from how each axis actually moves), not a fixed value
  - Coolant invert is controlled via `MIST_INVERT` and `FLOOD_INVERT` in the driver configuration

## 4. Ethernet controller: WIZnet W5500
**Datasheet:** [W5500](https://docs.wiznet.io/img/products/w5500/W5500_ds_v110e.pdf)
The Ethernet section requires slightly more careful routing of the MDI/MDO lines.
- It typically uses a 25 MHz crystal (e.g. HC49/US, often Extended on JLCPCB).
- **RJ45 connector**: the easiest path is a connector with integrated magnetics (e.g. HanRun HR911105A), which makes the job much simpler — i.e. you don't have to spread components around the board for the isolation transformer.
- **Power**: it runs at 3.3V; place `100nF` decoupling caps around every VCC pin on the chip! The W5500 draws up to 150mA under full load.
- **Reference schematic**: follow Figure 29 (page 61) in the official W5500 datasheet linked above ("W5500 Reference Schematic with RJ45"). Copy the passives from there: `49.9 Ohm` and `33 Ohm` resistors that are JLCPCB `Basic`.

## 5. Communication: SP3485EN-L/TR (RS485 for VFD and RS422 for the Pendant)
RectaBot v1.0 uses the **SP3485EN-L/TR** (MaxLinear) — a 3.3V RS-485/RS-422 transceiver. The advantage over the MAX485: it runs directly at 3.3V (no level shift needed), low power, up to 10 Mbps. **Datasheet:** [SP3485](https://www.maxlinear.com/SP3485)

**RS485 (Half Duplex for VFD/Modbus)** — 1× SP3485 (U19)
- Power **3.3V** (and a `100nF` decoupler near pin 8).
- RO (pin 1) to `GP25` (RP2350 RX).
- DI (pin 4) to `GP24` (RP2350 TX).
- RE (pin 2) and DE (pin 3) tied together and connected to the Modbus Direction pin `GP26`.
- A (pin 6) and B (pin 7) to connector **CN32** (`GND · A+ · B−`); **120Ω** terminator via jumper.
- **TVS protection:** `PSM712-LF-T7` (D4) on the A/B line **at the connector**, NOT next to the SP3485.
- No galvanic isolation in v1; if VFD noise becomes a problem, consider SI8621 + B0505S for v2.

**RS422 (Full Duplex for the Pendant display)** — 2× SP3485 (U21 TX, U22 RX)
- Although the SP3485 is not natively RS-422, it is used as two separate chips in unidirectional mode:
  - **U21 (TX):** RE=GND (always receive disabled), DE=VCC (always transmit enabled) → transmit only
  - **U22 (RX):** RE=GND (always receive enabled), DE=GND (always transmit disabled) → receive only
- U21's A/B outputs go to the pendant (pendant RX side) — differential pair 1.
- Z/Y (the A/B from U22's perspective) receive from the pendant (pendant TX side) — differential pair 2.
- **120Ω 0603 terminator** on the input side of U22 (R111).
- **TVS protection:** `PSM712-LF-T7` (D5, D6) on each pair — **at connector CN41** (the pendant header).
- Pins: `GP28` (UART0 TX → U21 DI), `GP29` (UART0 RX ← U22 RO).

## 6. Spindle 0-10V Converter + EN/DIR (CN39)

RectaBot v1 integrates a **0-10V analog speed reference** and **open-drain EN/DIR digital signals** for universal compatibility with most VFDs (Huanyang, Lapond, Delta, Hitachi, etc.).

### CN39 Pinout (4-pin KF2EDGR-3.5)
| Pin | Net | Function | Voltage |
|---|---|---|---|
| 1 | `VFD_10V` | Analog speed (0-10V) | 0-10V DC |
| 2 | `VFD_EN` | Run/Enable (active LOW open-drain) | 0V active / floating inactive |
| 3 | `VFD_DIR` | Direction (active LOW open-drain) | 0V active / floating inactive |
| 4 | `GND` | Signal/Analog ground | 0V |

### 6.1 PWM-to-0-10V Converter (LM358DR2G)

**Topology (non-inverting amplifier with a 2-stage RC filter + Zener clamp):**

- **U23 = LM358DR2G** (Basic, SOIC-8). VCC = 24V_IN (rail-to-rail is not an issue on a 24V supply).
- **2-stage RC filter:** R116 (10k) + C81 (100nF), R117 (10k) + C83 (100nF) → cutoff 159Hz × 2, attenuation 88dB at 25kHz PWM.
- **Gain network:** R122 (10k) + R128 (10k trim pot) + R120 (10k) → safe gain range **1.5-3.0** (max 9.9V from 3.3V PWM).
- **Overvoltage protection:** R123 (1kΩ) in series + **D7 = 1N4742A 12V Zener (TH, hand-soldered)** + C84 (10nF) → clamps to 12V max regardless of failure.
- **LED indicator:** U23B unity buffer follows VFD_10V → R121 (2k) → LED6 (4mA at 10V).

**Calibration:** tune trim pot R128 with the multimeter so that at 100% PWM you get exactly 10.0V on CN39 pin 1.

### 6.2 EN/DIR open-drain buffers (2× 2N7002)

**Topology (open-drain MOSFET buffer):**

- **Q1, Q2 = 2N7002** (Basic, SOT-23) N-MOSFET, 60V Vds rating.
- **R125, R126 (1kΩ)** gate series — current limit during transients.
- **R124, R127 (10kΩ)** gate pull-down — keeps the MOSFET OFF during MCU reset/boot (failsafe).
- **Source** pins to GND.
- **Drain** pins to CN39 pin 2 (VFD_EN) and pin 3 (VFD_DIR).

**Operational logic:**
| MCU GP30/GP31 | MOSFET | CN39 pin | VFD sees |
|---|---|---|---|
| HIGH (3.3V) | ON | Pulled to GND (~0V) | **ACTIVE** (sinking input triggered) |
| LOW (0V) | OFF | Floating (high-Z) | INACTIVE (VFD pull-up holds HIGH) |
| Reset/boot | OFF (pull-down failsafe) | Floating | INACTIVE ✓ |

**MCU protection:** the 2N7002 Drain blocks up to 60V → if the VFD has a 24V internal pull-up on the FOR/REV terminal, **voltage does NOT come back into the RP2350B pin**.

### 6.3 VFD compatibility

Sinking digital inputs (~85% of the market): Huanyang HY01/HY02, Lapond SVD-EM, ATO, Delta VFD-M/EL, Hitachi WJ200 — **work directly** with the 2N7002 open-drain.

Sourcing/PNP digital inputs (industrial, ~15%): Siemens G120, ABB ACS580, Schneider ATV — need an **external 2-channel relay module** ($3 on AliExpress). For v2, an **integrated relay tier** is planned (Omron G6K-2P-Y).

**Detailed instructions per VFD model:** see [VFD_Wiring_Guide.md](VFD_Wiring_Guide.md).

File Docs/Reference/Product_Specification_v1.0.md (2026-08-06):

# RectaBot v1.0 — Product Specification

**Industrial-grade 5-axis CNC controller with integrated network, USB, isolated I/O, and spindle 0-10V interface.**

---

## 📑 Table of Contents

- [Product Overview](#-product-overview)
- [Key Features](#-key-features)
  - [Motion Control](#motion-control)
  - [Spindle Control](#spindle-control-new-in-v10)
  - [Isolated I/O](#isolated-io)
  - [Connectivity](#connectivity)
  - [Power Distribution](#power-distribution)
  - [Safety & EMI](#safety--emi)
- [Connector Pinout](#-connector-pinout)
  - [Power & USB](#power--usb)
  - [Stepper Motors](#stepper-motors-x-y-z-a-b)
  - [Spindle / Laser](#spindle--laser)
  - [Isolated Inputs](#isolated-inputs-24v_iso-domain)
  - [Auxiliary / Communication](#auxiliary--communication)
- [Electrical Specifications](#-electrical-specifications)
  - [Power](#power)
  - [Stepper Outputs](#stepper-outputs-per-axis)
  - [Spindle 0-10V Output](#spindle-0-10v-output)
  - [Spindle EN/DIR Outputs](#spindle-endir-outputs)
  - [Isolated Inputs](#isolated-inputs)
  - [Communication](#communication)
- [Compliance & Reliability](#-compliance--reliability)
- [Compatibility](#-compatibility)
  - [Stepper Drivers](#stepper-drivers)
  - [VFD Compatibility](#vfd-variable-frequency-drives)
  - [Laser Modules](#laser-modules)
  - [CNC Machines](#cnc-machines)
- [Onboard Components Summary](#-onboard-components-summary)
- [Mechanical](#-mechanical)
- [Firmware](#-firmware)
- [In the Box](#-in-the-box)
- [Documentation](#-documentation)
- [Support](#-support)
- [Legal](#-legal)
- [Revision History](#-revision-history)

---

## 📦 Product Overview

RectaBot is a professional CNC mill controller designed for hobby-pro and small workshop applications. Built around the powerful **Raspberry Pi RP2350B** microcontroller running open-source **grblHAL** firmware, it combines industrial-grade isolation, multi-axis stepper control, and modern connectivity in a single 150×100mm PCB.

| Property | Value |
|---|---|
| **Model** | RectaBot v1.0 |
| **Form factor** | 150×100mm 4-layer PCB |
| **MCU** | Raspberry Pi RP2350B (QFN-80, dual ARM Cortex-M33 @ 150MHz) |
| **Firmware** | grblHAL (open-source) |
| **Power input** | 24V DC, 2A max |
| **Operating temperature** | -10°C to +60°C |
| **PCB layers** | 4 (top signal, GND plane, power plane, bottom signal) |
| **Input isolation** | Optical isolation on all 10 field inputs (LTV-217-B-G, 5kV rated, 24V_ISO domain). Outputs share MCU ground in v1. |

---

## 🎯 Key Features

### Motion Control
- ✅ **5-axis stepper control** (X, Y, Z, A, B) via PIO-based step generation
- ✅ **Common Anode** drive topology for DM556 / TB6600 / DM860 driver compatibility
- ✅ **5V logic-level** STEP/DIR/EN signals (via 74HC14D Schmitt trigger buffer)
- ✅ Hardware-accelerated step pulses up to **300kHz per axis**
- ✅ Y-axis auto-squaring (B-axis as ganged Y2)

### Spindle Control (NEW in v1.0)
- ✅ **0-10V analog speed output** for VFD compatibility (LM358 op-amp with trim calibration)
- ✅ **Open-drain Enable & Direction signals** (2N7002 MOSFET, 60V tolerant)
- ✅ **Overvoltage protection** (12V Zener clamp on 0-10V output)
- ✅ Compatible with **Huanyang, Lapond, Delta, ATO, Hitachi** VFDs out-of-the-box
- ✅ PWM range: 0-25kHz, supports laser modulation on shared output
- ✅ Visual brightness LED indicator follows actual VFD output

### Isolated I/O
- ✅ **10 optically isolated inputs** (24V_ISO domain, LTV-217 optocouplers, 5kV component rating)
  - 5× limit switches (X_MIN, Y_MIN, Z_MAX, A_MIN, B_MIN)
  - E-Stop, Probe, Cycle Start, Feed Hold, Door safety
- ✅ **3 auxiliary 5 V outputs** (Mist M7, Flood M8, Vacuum M62/M63) — signal level, 330 Ω
  series, 25 mA per pin. Drives optocoupler-input relay modules, and a Fotek SSR-40 DA
  switches directly (measured 3.11 V / ~5.9 mA on a 230 V lamp). The three outputs sit on
  three separate buffer chips, so one SSR per output can run at once — see
  [Pinout.md](Pinout.md)
- ✅ **24V_ISO isolated supply** (B2424S-2WR3, 2W isolated DC-DC)
- ✅ Hardware debounce (100nF parallel to optocoupler LED)

### Connectivity
- ✅ **Ethernet 10/100 Mbps** via W5500 + RJ45 with integrated magnetics
  - Bob Smith termination for EMI suppression
  - 100Ω diff impedance controlled TX/RX pairs
- ✅ **USB-C 2.0 Full-Speed** for programming, debugging, host control
  - VBUS detection on GP47
  - CC1/CC2 5.1kΩ pull-down (device mode)
  - 22Ω series termination on D+/D-
- ✅ **RS-485 Modbus** for VFD spindle and external I/O expansion (SP3485)
- ⚪ **RS-422 pendant interface** (CN41, full duplex, dual SP3485) — populated and pinned out on UART0, but **the firmware does not use it**: `MPG_ENABLE` and `KEYPAD_ENABLE` are off in `my_machine.h`, and nothing has been connected to it. Hardware only
- ✅ **MicroSD card** for G-code file storage and configuration

### Power Distribution
- ✅ **24V → 5V buck converter** (TPS5430DDAR, 3A capability)
- ✅ **5V → 3.3V LDO** (AMS1117-3.3, 800mA)
- ✅ **24V_ISO isolated rail** (83mA for opto LED inputs)
- ✅ **5 power LED indicators** (24V, 5V, 3V3, USB, ISO status)
- ✅ **+5V ORing diode** (SS54) — buck 5V and USB-C 5V coexist without back-feed

### Safety & EMI
- ✅ **4-layer stackup** with solid GND plane (L2) for return paths
- ✅ **PSM712 TVS arrays** on RS-485/422 + Bob Smith on RJ45/USB-C shells
- ✅ **Input-side isolation barrier** (2mm copper void) — separates MCU ground from 24V_ISO input domain. Stepper/Spindle/AUX outputs share MCU ground in v1.
- ✅ **Failsafe spindle defaults** during MCU reset (open-drain MOSFETs OFF by default)
- ✅ **12V Zener clamp** on spindle 0-10V output (protects VFD from MCU failure)

---

## 🔌 Connector Pinout

### Power & USB
| Connector | Type | Function |
|---|---|---|
| **CN42** | 2-pin screw (3.5mm) | 24V DC input |
| **USBC1** | USB-C | Programming, debug, host control |
| **RJ1** | RJ45 | Ethernet 10/100 Mbps |

### Stepper Motors (X, Y, Z, A, B)
| Connector | Pinout | Function |
|---|---|---|
| **CN34** | X axis (4-pin) | +5V, STEP, DIR, EN (5V Common Anode) |
| **CN35** | Y axis (4-pin) | +5V, STEP, DIR, EN |
| **CN36** | Z axis (4-pin) | +5V, STEP, DIR, EN |
| **CN37** | A axis (4-pin) | +5V, STEP, DIR, EN |
| **CN38** | B axis (4-pin) | +5V, STEP, DIR, EN (Y2 tandem) |

**There is no GND pin on a stepper connector, and there is not meant to be.** Common anode
means pin 1 feeds the driver's `PUL+`/`DIR+`/`ENA+` together, and the on-board 74HC14D pulls
`PUL−`/`DIR−`/`ENA−` down — the signal lines are the return path. A board that put GND here
instead would be wired common cathode, which this one is not.

### Spindle / Laser
| Connector | Pinout | Function |
|---|---|---|
| **CN39** | 4-pin (3.5mm) | VFD_10V, VFD_EN, VFD_DIR, GND |
| **CN33** | 2-pin (3.5mm) | Laser PWM, GND |

### Isolated Inputs (24V_ISO domain)
| Connector | Function |
|---|---|
| **CN22** | DOOR (safety door input, GP42) |
| **CN23** | FEED HOLD |
| **CN24** | CYCLE START |
| **CN25** | PROBE |
| **CN26** | E-STOP |
| **CN27** | B_LIMIT |
| **CN28** | A_LIMIT |
| **CN29** | Z_LIMIT |
| **CN30** | Y_LIMIT |
| **CN31** | X_LIMIT |

### Auxiliary / Communication
| Connector | Function |
|---|---|
| **CN40** | AUX (+5V, VAC, FLOOD, MIST, GND) — 5-pin, 5 V signal outputs for relay modules |
| **CN41** | RS-422 Pendant (24V/TX+/TX−/RX+/RX−/GND) — 6-pin |
| **CN32** | RS-485 Modbus (GND/A+/B-) |
| **CARD1** | MicroSD socket (SPI mode) |

---

## ⚙️ Electrical Specifications

### Power
| Parameter | Min | Typ | Max | Unit |
|---|---|---|---|---|
| Input voltage | 12 | 24 | 30 | V DC |
| Input current (no load) | — | 150 | 250 | mA |
| Input current (typical) | — | 400 | 800 | mA |
| Input current (worst case all outputs active) | — | — | 2000 | mA |
| 5V rail output | 4.9 | 5.0 | 5.1 | V |
| 3.3V rail output | 3.25 | 3.30 | 3.35 | V |
| 24V_ISO rail output | 23 | 24 | 25 | V |
| 24V_ISO max current | — | — | 83 | mA |

### Stepper Outputs (per axis)
| Parameter | Value |
|---|---|
| Logic level (after 74HC14D) | 5V CMOS |
| Output drive current | ±25mA peak per pin |
| STEP pulse minimum width | 1µs |
| STEP frequency max | 300kHz |
| DIR setup time | 5µs (configurable) |

### Spindle 0-10V Output
| Parameter | Value |
|---|---|
| Output voltage range | 0 - 10V DC |
| Output linearity | ±0.5% (after trim calibration) |
| Output impedance | ~1kΩ (series limit + Zener) |
| Output ripple at 25kHz PWM | <5mV |
| Trim adjustment range | Gain 1.5x to 3.0x |
| Overvoltage clamp | 12V (1N4742A Zener) |
| Settling time (0→10V) | <20ms |

### Spindle EN/DIR Outputs
| Parameter | Value |
|---|---|
| Output type | Open-drain (N-MOSFET) |
| Max sink current | 300mA |
| Max applied voltage | 60V DC |
| ON-state Vds | <100mV at 100mA |
| OFF-state leakage | <1µA |
| Failsafe default (MCU reset) | OFF (high-Z) via pull-down |

### Isolated Inputs
| Parameter | Value |
|---|---|
| Input voltage range | 12-30V DC (24V nominal) |
| Input current | ~5mA at 24V |
| Isolation rating | 5kV (LTV-217) |
| Response time (with debounce cap) | <1ms |
| Logic threshold | Optocoupler current ~3mA |

### Communication
| Interface | Speed | Distance | Notes |
|---|---|---|---|
| Ethernet | 100Mbps | 100m | RJ45 with integrated magnetics |
| USB-C | 12Mbps (Full-Speed) | 3m | Device mode, CDC + UF2 |
| RS-485 Modbus | up to 1Mbps | 1200m | Half-duplex, 120Ω termination |
| RS-422 Pendant | up to 1Mbps | 100m | Full-duplex differential |
| SPI (microSD) | 25MHz | <30mm | Mode 0, on-board |

---

## 🛡️ Compliance & Reliability

### EMI/EMC Design
- 4-layer PCB with solid GND plane for low-impedance return paths
- Edge stitching vias every 5mm (Faraday cage effect)
- Diff pair impedance control (USB 90Ω, Ethernet 100Ω, RS-422/485 100Ω)
- TVS protection on all external connectors (RS-485, RS-422, USB shell, Ethernet shell)
- Bob Smith termination on Ethernet RJ45 + USB-C shells

### Protection Features
- ⚠️ Note: the 24V input has **no** reverse-polarity protection in v1 — double-check polarity before powering on
- ESD protection on USB data lines (22Ω series + Bob Smith chassis coupling)
- TVS arrays on RS-485/422 lines (PSM712-LF)
- Optical isolation on all field inputs (LTV-217-B-G, 5kV component rating); outputs share MCU ground in v1
- Spindle output overvoltage clamp (12V Zener)
- Open-drain MOSFET protection for EN/DIR (60V tolerance)
- Failsafe spindle OFF during MCU reset/boot

### Quality Standards
- **CE/RoHS compliant** components (Pb-free, halogen-free where available)
- **Industrial-grade** electrolytics and ceramics (X7R dielectric)
- **Operating range:** -10°C to +60°C (component-limited)
- **Storage range:** -25°C to +85°C

---

## 🧰 Compatibility

### Stepper Drivers
- ✅ Leadshine **DM556** (most common)
- ✅ Leadshine **DM860**
- ✅ MakerBase **TB6600**
- ✅ DQ542MA, DQ860MA
- ✅ Any Common Anode optocoupler driver (5V signal)

### VFD (Variable Frequency Drives)
- ✅ **Huanyang** HY01/HY02 (most common, 0-10V + RUN/DIR)
- ✅ **Lapond** SVD-EM series
- ✅ **Delta** VFD-M, VFD-EL
- ✅ **ATO** generic VFDs
- ✅ **Hitachi** WJ200
- ⚠️ **Siemens G120, ABB ACS580** (industrial PNP): requires external relay module
- ✅ Modbus RS-485 spindle control (any VFD with Modbus support)

### Laser Modules
- ✅ Diode laser modules with TTL PWM input (Sculpfun, Atomstack, NEJE)
- ✅ Up to 25kHz PWM modulation rate
- ✅ 3.3V TTL signal level

### CNC Machines
- ✅ Router-style mills (drewno, MDF, aluminijum)
- ✅ Plasma cutters (with appropriate driver interface)
- ✅ Engraving machines
- ✅ XY plotters and pen-plotters
- ⚠️ Large industrial machines: confirm motor driver compatibility

---

## 🔬 Onboard Components Summary

### Critical IC's
| Designator | Part | Function |
|---|---|---|
| U1 | TPS5430DDAR | 24V→5V buck converter (3A) |
| U2 | AMS1117-3.3 | 5V→3.3V LDO (800mA) |
| U3 | B2424S-2WR3 | Isolated 24V DC/DC for I/O domain |
| U4 | RP2350B | Main MCU (dual M33 @ 150MHz, 48 GPIO) |
| U5 | W5500 | Ethernet controller (SPI) |
| U6 | W25Q128JVSIQ | 128Mbit (16MB) QSPI flash |
| U7, U10, U15 | 74HC14D | Stepper level shifter (3.3V→5V) |
| U8-U20 | LTV-217-B-G | Isolated input optocouplers (×10) |
| U19, U21, U22 | SP3485EN-L/TR | RS-485/422 transceivers (×3) |
| U23 | LM358DR2G | 0-10V spindle op-amp |
| Q1, Q2 | 2N7002 | Spindle EN/DIR open-drain buffers |
| RJ1 | J1B1211CCD | Integrated RJ45 + magnetics (WIZnet) |

### Protection & Filtering
- 3× PSM712-LF-T7 TVS arrays (RS-485, RS-422)
- 1× 1N4742A Zener (spindle output clamp)
- 1× SS54 Schottky (+5V ORing)
- 2× SS34 Schottky (buck output)
- 1× 1nF/2kV ceramic (Bob Smith chassis coupling)
- 2× crystal oscillators (12MHz MCU, 25MHz Ethernet)

---

## 📐 Mechanical

| Property | Value |
|---|---|
| PCB dimensions | 150 × 100 mm |
| PCB thickness | 1.6 mm |
| Copper weight | 1oz outer / 0.5oz inner |
| Surface finish | HASL (lead-free) or ENIG |
| Solder mask | Green (default), other colors available |
| Silkscreen | White, with component reference designators |
| Mounting holes | 5× total — 4× M3 (3.2mm drill) at corners + 1× central support hole on the diagonal (3.5mm drill, 7.5mm annular pad) |
| Mounting hole keepout | 6mm clearance |
| Connector spacing | All field connectors on board edges |

### Connector Specifications
- **Screw terminals:** KEFA KF2EDGR 3.5mm pitch (3/4/5/6 pin variants) — TH, soldered manually
- **Ethernet:** WIZnet J1B1211CCD RJ45 with shielded shell + integrated magnetics — TH, soldered manually
- **USB-C:** Korean Hanyong TYPE-C-31-M-12 (24-pin SMD with TH alignment posts) — **SMT, JLCPCB assembly**
- **MicroSD:** Push-push SMD socket — SMT, JLCPCB assembly

---

## 🔧 Firmware

### grblHAL Configuration
- **Board map:** `Firmware/boards/my_machine_map.h`
- **Steps:** configurable per axis via `$100-$104`
- **Max rate:** configurable per axis via `$110-$114`
- **Acceleration:** configurable per axis via `$120-$124`
- **Max spindle RPM:** `$30` (default 24000)
- **Invert masks (validated):** `$2=0` (step — Common Anode needs no invert), `$4` = enable invert on all axes (7/15/31 for 3/4/5-axis), `$5=0` (limit), `$6=1` (probe). `$3` (direction) is per-machine.

### Supported G-code
- G0-G3 (rapid, linear, arc moves)
- G4 (dwell)
- G10 (coordinate system)
- G17-G19 (plane selection)
- G20/G21 (inch/mm)
- G28/G30 (home)
- G38.x (probe)
- G54-G59 (coordinate systems)
- G90/G91 (absolute/relative)
- G92 (set position)
- G93/G94 (inverse/units per min)
- M0-M2 (program flow)
- M3/M4/M5 (spindle on CW/CCW/off)
- M7/M8/M9 (mist, flood, coolant off)
- M30 (program end)
- M62/M63 (auxiliary output control)

### Real-time Commands
- `?` Status query (position, feed, spindle)
- `~` Cycle resume
- `!` Feed hold
- `Ctrl-X` Soft reset

### Communication Modes
- USB CDC (default, virtual serial)
- Ethernet TCP (Telnet on port 23, websocket on port 80)
- Ethernet UDP (broadcast for discovery)

---

## 📦 In the Box

- 1× RectaBot v1.0 PCB (assembled)
- Quick Start Guide
- Connector pinout reference card
- Link to online documentation

### Optional Accessories (separately sold)
- Pre-made wiring harness for common VFDs
- Power supply 24V/5A
- Enclosure (DIN rail or panel mount)

---

## 📚 Documentation

- [Pinout Reference](Pinout.md)
- [Hardware Design Guidelines](Hardware_Design_Guidelines.md)
- [Schematic References](Schematic_References.md)
- [VFD Wiring Guide](VFD_Wiring_Guide.md)

---

## 🆘 Support

- **Website:** rectabot.org
- **GitHub:** github.com/rectabot
- **Email:** support@rectabot.org

---

## ⚖️ Legal

- **License (Hardware):** CERN-OHL-S v2 (Strong reciprocal open hardware)
- **License (Firmware):** GPL v3 (grblHAL base)
- **Warranty:** 12 months limited (EU consumer rights)
- **CE marking:** Self-certified per EMC Directive 2014/30/EU (DoC available)
- **RoHS:** Compliant (lead-free components used where available)

---

## 📊 Revision History

| Version | Date | Changes |
|---|---|---|
| **v1.0** | 2026-05-28 | Initial production release with integrated 0-10V spindle interface, 2N7002 EN/DIR protection, Zener clamp |
| v0.9 | 2026-04-20 | Pre-production prototype (no 0-10V, no protection MOSFETs) |
| v0.5 | 2026-03-15 | Schematic complete, layout draft |
| v0.1 | 2026-02-01 | Concept phase |

---

*RectaBot is an open-source project designed and manufactured in Serbia by Filip Perić.*

*Document version 1.0 — last updated 2026-05-28.*

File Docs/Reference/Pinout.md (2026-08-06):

# RP2350B Pinmap (RectaBot v1.0)

The RP2350B (QFN-80) has 48 GPIO pins (GP0-GP47).

**Level shift 3.3V → 5V:** Stepper signals (STEP/DIR/EN) and coolant outputs (VAC/FLOOD/MIST) pass through the **74HC14D** (Schmitt-trigger HEX inverter, Basic part on JLCPCB). Three 74HC14D chips (U7, U10, U15) cover 18 signals.

**The 74HC14D inverts the signal, but in Common Anode mode this is already accounted for** — no firmware STEP invert is needed. Validated on bench (TB6600 + NEMA17, smooth both directions, no missed steps up to F2000):
- `$2=0` — STEP_INVERT_MASK. With `$2=0` the 74HC14D output idles HIGH (OPT− high → opto OFF) and each step pulse briefly pulls OPT− low (opto ON) — correct for Common Anode. Setting `$2`≠0 would hold the input opto continuously ON at idle and likely cause missed steps at speed.
- `$3` — DIRECTION_INVERT_MASK is **per-machine** (depends on wiring/mechanics). Jog each axis and flip its bit so X+/Y+/Z+ move the right way — do not treat it as a fixed value.
- `$4=15` — STEPPER_ENABLE_INVERT_MASK. The 74HC14D inverts EN, so enable is inverted on every axis: **7 = 3-axis, 15 = 4-axis, 31 = 5-axis** (reference board is 4-axis → 15).
- `$5=0` — LIMIT invert OFF (the LTV-217 opto inputs already read active-low). `$6=1` — PROBE invert ON.
- Coolant invert via driver configuration

Stepper drivers operate in **Common Anode** mode: +5V on OPT+, the 74HC14D pulls OPT− to GND. Validated with TB6600; verified-under-load values (and any driver-specific differences, e.g. DM-series) to be confirmed when machining.

**Input galvanic isolation:** 10 isolated inputs via **LTV-217-B-G** optocouplers (U8-U20), powered from **+24V_ISO** (B2424S-2WR3 isolated DC/DC). GND_ISO is separated from GND by a 2mm copper void barrier.

**Input wiring (each connector: `24V · GND · SIG`):** the inputs are **sinking (active LOW)** — same convention as the VFD outputs.
- **Mechanical switch** (limit / E-stop): wire between **GND** and **SIG**. The 24V pin is not needed.
- **Inductive sensor — NPN (sinking)**: use all three pins — **24V** (power) + **GND** + **SIG**. The sensor switches SIG to GND.
- **PNP (sourcing) sensors are not directly compatible** (they drive SIG to 24V, so no current flows through the opto LED and the input never sees them) — use an external relay module, as with PNP VFDs.

**AUX output wiring — SSR (`CN40`: `+5V · VAC · FLOOD · MIST · GND`):** the coolant
outputs are **Common Anode, exactly like the stepper drivers**. Wire the SSR control
input between **`+5V` (pin 1)** and the signal pin — **never between the signal pin and
`GND`**.

| SSR control terminal | CN40 pin |
| :--- | :--- |
| `+` | **1** — `+5V` |
| `−` | **2** `VAC` · **3** `FLOOD` · **4** `MIST` |

Worked example, a Fotek SSR-40 DA running a mains lamp on `M7` — built and run, not
sketched:

| SSR terminal | to |
| :--- | :--- |
| **1** | 230 V live in |
| **2** | 230 V out → load → neutral |
| **3** (control `+`) | `CN40` pin 1 — `+5V` |
| **4** (control `−`) | `CN40` pin 4 — `MIST` |

Switches from `M7`/`M9`, from a sender's coolant button, and holds up under repeated
rapid on/off.

The 74HC14D inverts, so each coolant pin **idles HIGH (~5 V) and is pulled LOW when the
M-code switches the output on** — measured on the reference board: ~5 V at idle, ~0 V
under `M7`, back to ~5 V after `M9`. Wiring the SSR to `GND` instead inverts the whole
thing: the relay is **energised whenever the machine sits idle** and switches **off** the
moment `M7`/`M8`/`M62` runs. Nothing warns you — the flood pump simply runs all night.

#### ⚠️ Which relays these outputs can actually drive

Each output is a 74HC14D channel behind a **330 Ω** series resistor (`R45`, `R63`, `R91`),
the same arrangement that feeds the optocoupler in a DM556. Two figures from the datasheet
matter and they are not the same thing: **4 mA** is where `VOL` is *guaranteed* — the DC
test point — and **25 mA per pin** is the absolute maximum. Drawing more than 4 mA is not
an overload; it only means the datasheet stops promising a number.

**Measured on the reference board, with a Fotek SSR-40 DA switching a 230 V lamp:**

| | |
| :--- | :--- |
| Pin, open circuit | **5.07 V** |
| Across the relay's control input, with it connected | **3.11 V** |
| Remainder across the 330 Ω → current | 1.96 V → **~5.9 mA** |
| Implied `VOL` (5.07 − 3.11 − 1.96) | **≈ 0 V** — the output is not straining |
| Result | **It switches the lamp.** |

So a Fotek — a "control 3–32 VDC" input, meaning an internal current regulator that needs
3 V at its own terminals — gets what it needs, clearing its 3 V minimum. At 5.9 mA the
output still pulls essentially to ground, and there is roughly 4× headroom to the 25 mA
limit. What the 330 Ω sets is how much voltage is left for the relay, not whether the chip
can cope.

**All three outputs at once.** `MIST`, `FLOOD` and `VAC` are not three gates of one chip —
each sits on the last inverter of a *different* 74HC14D. Traced through the fabrication
netlist:

| Output | Series resistor | Inverter |
| :--- | :--- | :--- |
| `MIST_5V` (`M7`) | `R45` | **U7** pin 12 |
| `FLOOD_5V` (`M8`) | `R63` | **U10** pin 12 |
| `VAC_5V` (`M62`/`M63`) | `R91` | **U15** pin 12 |

So a second and a third relay add nothing to the package already carrying the first: each
5.9 mA stays on its own chip's ground pin, against the same 25 mA per-pin limit, and the
five stepper channels sharing each chip are untouched either way. What the three outputs
do share is `CN40` pin 1 — three Foteks draw **~17.7 mA** in total from the `+5V` rail,
which is negligible beside what that rail already feeds the buffers.

The caveat that remains is per-unit, not per-count: the **3.11 V** measured above sits just
over the Fotek's 3 V minimum, and that margin is a property of the individual relay — it
does not shrink as you add more. Counterfeit Foteks are common, so **check that each new
one actually triggers before building it in.**
*(Chip assignment read from the netlist; the current figures are the single-relay
measurement above carried across, not three relays measured together.)*

**The load this was drawn for** is anything whose input is an optocoupler — a relay/SSR
module with
a logic-level `IN` pin drawing ≤ 5 mA. Those have a gain stage: a few mA from this pin
lights an LED, whose transistor then pulls the 70–80 mA of coil current from the module's
own `VCC`. Note that DIN-rail interface relays (Phoenix Contact PLC-INTERFACE, Weidmüller
TERMSERIES, Wago 859, Omron G3RV-SR) use that same optocoupler input but are specified for
PLC outputs sourcing half an amp, so many of their 5 V models ask 10–15 mA. Check the
figure, not the brand.

**For a relay that will not trigger** — one needing more voltage than the 330 Ω leaves —
interpose a driver: a P-channel
MOSFET (e.g. AO3401) high side: source to `+5V`, gate to the signal pin, drain to the SSR
input, SSR return to `GND`. The gate draws no current, so the 330 Ω costs nothing and the
relay sees the full 5 V. The active-low signal suits a P-channel part directly.
*(Reasoned from the numbers above, not built and measured.)*

### NC or NO — and why NC is the one to ship

With **`$5=0`** an input reads **triggered when the circuit is OPEN**. So on the
`GND · SIG` wiring above:

| Device | `$5` | Broken wire behaves as |
|---|---|---|
| **NC** (normally closed) — recommended | `0` | **triggered → machine stops** ✅ |
| NO (normally open) | invert that axis | nothing — the fault is invisible ⚠️ |

That is the whole argument for NC: a cut wire, a loose terminal or a corroded
contact looks exactly like a tripped limit, so the machine refuses to move instead
of running blind past its own end stops. A NO switch fails silent — you find out
when the gantry does.

For inductive sensors the same rule picks the suffix: **`LJ12A3-4-Z/AX` (NPN NC)**
matches `$5=0`; `/BX` (NPN NO) needs `$5` inverted for that axis. `/AY` and `/BY`
are PNP and need a relay module either way.

`$5` is a per-axis mask, so a machine may mix types if it must — but a mixed
machine has mixed failure modes, which is its own kind of expensive.

| Function | RP2350 Pin | Notes |
| :--- | :--- | :--- |
| **Auxiliary outputs** | | Through 74HC14D FREE channels + 330 Ω — see *AUX output wiring* above |
| VAC | `GP0` | Through 74HC14D (inverted) → relay module, grblHAL M62/M63 |
| FLOOD | `GP1` | Through 74HC14D (inverted) → relay module, grblHAL M8/M9 |
| MIST | `GP2` | Through 74HC14D (inverted) → relay module, grblHAL M7/M9 |
| SD Card Detect | `GP3` | MicroSD socket CD switch (active LOW when card inserted) |
| **W5500 Ethernet (SPI0)** | | |
| MISO | `GP4` | SPI0 RX |
| SCSn | `GP5` | SPI0 CS |
| SCLK | `GP6` | SPI0 SCK |
| MOSI | `GP7` | SPI0 TX |
| **X axis** | | Through 74HC14D |
| STEP_X → STEP_X_5V | `GP8` | 74HC14D input/output |
| DIR_X → DIR_X_5V | `GP13` | 74HC14D input/output |
| EN_X → EN_X_5V | `GP18` | 74HC14D input/output |
| **Y axis** | | Through 74HC14D |
| STEP_Y → STEP_Y_5V | `GP9` | 74HC14D input/output |
| DIR_Y → DIR_Y_5V | `GP14` | 74HC14D input/output |
| EN_Y → EN_Y_5V | `GP19` | 74HC14D input/output |
| **Z axis** | | Through 74HC14D |
| STEP_Z → STEP_Z_5V | `GP10` | 74HC14D input/output |
| DIR_Z → DIR_Z_5V | `GP15` | 74HC14D input/output |
| EN_Z → EN_Z_5V | `GP20` | 74HC14D input/output |
| **A axis** | | Through 74HC14D |
| STEP_A → STEP_A_5V | `GP11` | 74HC14D input/output |
| DIR_A → DIR_A_5V | `GP16` | 74HC14D input/output |
| EN_A → EN_A_5V | `GP21` | 74HC14D input/output |
| **B axis (Y2 tandem)** | | Through 74HC14D |
| STEP_B → STEP_B_5V | `GP12` | 74HC14D input/output |
| DIR_B → DIR_B_5V | `GP17` | 74HC14D input/output |
| EN_B → EN_B_5V | `GP22` | 74HC14D input/output |
| **W5500 Ethernet** | | |
| W5500_INT (INTn) | `GP23` | Interrupt |
| **RS485 Modbus** | UART1 | MAX485 or external module |
| RS485 TX | `GP24` | UART1 TX → MAX485 DI |
| RS485 RX | `GP25` | UART1 RX ← MAX485 RO |
| RS485 DE/RE | `GP26` | Direction control |
| **Spindle / Laser** | | |
| Spindle PWM / Laser PWM | `GP27` | PWM for VFD and laser diode module (3.3V TTL, shared with CN39 + CN33). For VFD it goes through the LM358 0-10V converter; for laser, directly to CN33. |
| RS422 TX (Pendant) | `GP28` | UART0 TX → SP3485 Chip1 (TX hardwired) |
| RS422 RX (Pendant) | `GP29` | UART0 RX ← SP3485 Chip2 (RX hardwired) |
| Spindle Enable (VFD_EN) | `GP30` | Enable VFD → 2N7002 open-drain Q1 → CN39 pin 2 (VFD_EN, active LOW open-drain) |
| Spindle Dir (VFD_DIR) | `GP31` | Direction VFD → 2N7002 open-drain Q2 → CN39 pin 3 (VFD_DIR, active LOW open-drain) |
| W5500_RST (RSTn) | `GP32` | W5500 reset, 4.7kΩ pull-up |
| **Limits / Control inputs** | | Via LTV-217-B-G opto, 24V_ISO |
| X_MIN | `GP33` | X-axis limit switch |
| Y_MIN | `GP34` | Y-axis limit switch |
| Z_MAX | `GP35` | Z-axis limit switch (homing up) |
| A_MIN | `GP36` | A-axis limit switch — free on 4/5-axis builds, see below |
| B_MIN | `GP37` | B-axis limit switch (Y2 auto-square) |
| ESTOP | `GP38` | Emergency Stop → grblHAL alarm |
| PROBE | `GP39` | Tool length probe |
| CYCLE_START | `GP40` | Cycle start |
| FEED_HOLD | `GP41` | Pause |
| DOOR | `GP42` | Safety door input (grblHAL `SAFETY_DOOR`): opening the door holds the machine until closed. Neutral default (no forced invert) — set `$14` DOOR bit to match the switch (NO/NC). |
| **SD card (SPI1)** | | |
| SD MOSI | `GP43` | SPI1 TX |
| SD MISO | `GP44` | SPI1 RX |
| SD CS | `GP45` | SPI1 CSN |
| SD CLK | `GP46` | SPI1 SCK |
| VBUS_DET | `GP47` | USB VBUS detect, 10kΩ/10kΩ divider (R6/R8) → 2.5V (above VIH=2.15V) |

## A_MIN (`GP36`) is a spare isolated input on a 4-axis machine

A rotary A axis is not homed, so it has no limit switch and its input sits unused. That
makes `GP36` the one 24 V isolated input still free on a fully populated board — every
`AUXINPUT` is spoken for (E-stop, probe, cycle start, feed hold, door) — and it goes
through the same LTV-217 optocoupler as the other limits. A mechanical **tool setter** is
what it is worth spending on: a fixed pad the machine touches off against, which is what
tool-length offsets need and what the probe input alone cannot give you, since the probe
travels with the spindle.

When it is free, and when it is not:

| build | `GP36` |
|---|---|
| 4- and 5-axis, any Y arrangement | **free** — A takes motor 3, so an auto-squared Y2 lands on `GP37` |
| 3-axis, single or plain ganged Y | **free** — nothing claims it |
| 3-axis, auto-squared Y | **taken** — the second Y home switch is here |

grblHAL assigns a ganged motor to the highest channel, which is why the same wire lands on
a different pad depending on axis count. The board map does this for you; the table is
just so you can check the pad before wiring to it.

**The pad is wired; the firmware images do not read it.** None of the published builds
enable a tool setter, so this is a build you make yourself — the hardware is here for it,
which is the part you cannot add later.

Declare `GP36` as an aux input in the board map and define `TOOLSETTER_PIN 36` /
`TOOLSETTER_ENABLE 1`, guarded so an auto-squared 3-axis build does not claim the pad twice,
and grblHAL registers a second probe of its own, separate from `PROBE`. Settings survive the
flash — the tool setter's invert / pull-up / auto-select flags are bits in a word that
already exists, so the settings structure does not grow. See `variants/CONFIG.md` for how a
variant is built, and for the options where that is *not* true.

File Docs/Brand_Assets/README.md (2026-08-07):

# RectaBot Brand Assets

Logo files for the RectaBot CNC controller project.

## License & brand usage

The RectaBot **hardware, firmware and documentation are open** (see `LICENSE`,
`LICENSE.hardware`, and the firmware repo). The **name "RectaBot", the related
product names in the same family (the "Recta" marks), and the logo/wordmark are
NOT open-licensed** — they are the project's brand identity.

**Copyright (c) 2026 Filip Perić. All rights reserved** for the RectaBot name, the
"Recta" product-family names, and the marks in this folder (the `rectabot` wordmark,
the `r` icon, the lockups, and the favicon).

### You MAY (no permission needed)
- Use the name and logo to **refer to** the genuine RectaBot project — "works with
  RectaBot", a link back to rectabot.org, reviews, tutorials, articles.
- Reproduce the logo **unmodified** to identify the official project.

### You MAY NOT (without written permission)
- Put the RectaBot name or logo on **your own hardware, firmware, or products** —
  including boards you manufacture from the open design files.
- Use the marks in a way that implies the RectaBot project **endorses, sponsors,
  or is affiliated** with your product.
- Use a **confusingly similar** name or logo (a modified wordmark, a similar `r`
  icon, the same cyan lockup) for a competing or derivative product.

### If you build on the open hardware design
The design files are yours to use under CERN-OHL-S v2 — **but the brand is not.**
**Rebrand your product:** use your own name and logo, and remove the RectaBot marks
from silkscreen, docs, and UI. This keeps the open design open while avoiding
confusion about who stands behind a given board.

Questions or permission requests: **hello@rectabot.org**

> *Why the brand is reserved while everything else is open: the design is meant to
> be shared and built on; the brand is how people know a board came from us and can
> trust its support and updates. Keeping the trademark while opening the tech is the
> standard open-project model — Arduino, Raspberry Pi and Linux all do exactly this.*

---

## Files

### Wordmark variants

| File | Use |
|---|---|
| `rectabot-wordmark-cyan.svg` | Primary wordmark for dark backgrounds (cyan-400 `#22d3ee`) |
| `rectabot-wordmark-white.svg` | PCB silkscreen, dark backgrounds |
| `rectabot-wordmark-dark.svg` | Light backgrounds, print, documents |

### Icon variants (square)

| File | Use |
|---|---|
| `rectabot-icon-cyan.svg` | Dark `#020617` tile with a cyan `r`. For light backgrounds. |
| `rectabot-icon-light.svg` | Cyan `#22d3ee` tile with a dark `r`. For dark backgrounds. |

The two names are not consistent with each other — in `-cyan` the cyan thing is
the letter, in `-light` it is the tile. **Go by the description, not the
filename.** The rule is simply: pick the tile that stands out against the surface
you are putting it on.

Every icon has **one cut corner, top left**, at the radius the letter's own elbow
is drawn with, so the corner and the elbow read as a single gesture. A tile with
four rounded corners is not the mark — if you find yourself writing
`rounded-lg`, use the asset instead.

### Combined lockup

| File | Use |
|---|---|
| `rectabot-lockup-horizontal.svg` | Icon + wordmark, for headers and banners |

### Other

| File | Use |
|---|---|
| `favicon.svg` | Favicon for web (64×64) |
| `rectabot-orbitron.svg` | Original wordmark master file |

---

## Typography

The wordmark uses **Orbitron** (Google Fonts, SIL Open Font License) at weight 900, letter-spacing `0.06em`, always lowercase.

## Color palette

| Token | Hex |
|---|---|
| Cyan 400 (primary) | `#22d3ee` |
| Slate 950 (background) | `#020617` |
| Slate 100 (text) | `#f1f5f9` |
| Cyan 300 (highlight) | `#67e8f9` |

---

## Usage examples

### HTML favicon

```html
<link rel="icon" type="image/svg+xml" href="favicon.svg">
```

### HTML wordmark

```html
<a href="#" style="display: flex; align-items: center; gap: 12px;">
  <img src="rectabot-icon-cyan.svg" width="36" height="36" alt="RectaBot">
  <img src="rectabot-wordmark-cyan.svg" height="24" alt="rectabot">
</a>
```

### Font loading (for inline text using Orbitron)

```html
<link rel="preconnect" href="https://fonts.googleapis.com">
<link rel="preconnect" href="https://fonts.gstatic.com" crossorigin>
<link href="https://fonts.googleapis.com/css2?family=Orbitron:wght@400;700;900&display=swap"
      rel="stylesheet">
```

---

## Do

- Use lowercase `rectabot` in the wordmark.
- Keep the letter-spacing at `0.06em`.
- Leave generous clear space around the mark (see below).
- Use the white wordmark on PCB silkscreen.
- Use cyan-400 (`#22d3ee`) as the accent colour.
- Use the icon rather than the wordmark when space is tight.
- **Use the asset files.** Do not rebuild the mark in CSS or by setting an `r` in
  a rounded box — that loses the single cut corner, which is the mark.

## Don't

- Don't write `RECTABOT` or `Rectabot` in the marks. In body text, "RectaBot" is fine.
- Don't substitute other fonts.
- Don't rotate, skew, stretch or compress the logo.
- Don't recolour it outside the palette above.
- Don't apply drop shadows, gradients or 3D effects.

---

## Minimum sizes

- **Wordmark:** 80px wide minimum (for readability)
- **Icon:** 16px × 16px minimum (favicon size)
- **Lockup:** 200px wide minimum

## Clear space

- Around wordmark: 0.5× the height of the `r` glyph
- Around icon: 0.25× the icon side

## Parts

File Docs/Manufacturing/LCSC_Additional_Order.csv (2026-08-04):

LCSC Part Number | Manufacturer Part | Description | Need per 5 boards | Order Qty (MOQ adjusted) | Unit Price USD | Total USD | Notes
 |  | === TH COMPONENTS ===
C2873969 | KM1E101M0611 | 100uF 25V Aluminum electrolytic BD6.0-P2.50 | 5 | 50 | 0.0193 | 0.97 | C7 - main input electrolytic (MOQ 50; 45 spare)
C2976624 | CC3D102KC2IEB46U31MF | 1nF 2kV Ceramic disc L6.8-W2.6-P5.08 | 5 | 20 | 0.0378 | 0.76 | C61 - Bob Smith chassis coupling cap (MOQ 20)
C140853 | 1N4742A | Zener Diode 12V 1W DO-41 | 5 | 5 | 0.1019 | 0.51 | D7 - spindle overvoltage clamp
C2691448 | PZ254V-11-04P | 2.54mm pitch 4-pin straight pin header | 5 | 20 | 0.0266 | 0.53 | H1 - SWD debug header (MOQ 20)
C6630214 | PV37W103C01B00 | Bourns 10k trim pot PV37W | 5 | 5 | 3.00 | 15.00 | R128 - spindle 0-10V gain trim (Bourns)
C910371 | J1B1211CCD | Pulse RJ45 with integrated magnetics | 5 | 5 | 2.7284 | 13.64 | RJ1 - Ethernet jack with integrated magnetics
C5369487 | B2424S-2WR3 | YLPTEC Isolated DC/DC 24V-24V 2W SIP-4 | 5 | 5 | 1.2593 | 6.30 | U3 - isolated 24V->24V_ISO supply for opto LEDs
 |  |  | SUBTOTAL TH: |  |  | 37.71
 |  | === FEMALE KEFA CONNECTORS (TH | PCB side) ===
C441171 | KF2EDGR-3.5-2P | KEFA 2-pin female terminal block 3.5mm | 10 | 10 | 0.0497 | 0.50 | CN33 + CN42
C441172 | KF2EDGR-3.5-3P | KEFA 3-pin female terminal block 3.5mm | 55 | 55 | 0.0582 | 3.20 | CN22-CN32
C441173 | KF2EDGR-3.5-4P | KEFA 4-pin female terminal block 3.5mm | 30 | 30 | 0.0875 | 2.63 | CN34-CN39
C441174 | KF2EDGR-3.5-5P | KEFA 5-pin female terminal block 3.5mm | 5 | 5 | 0.1241 | 0.62 | CN40
C441175 | KF2EDGR-3.5-6P | KEFA 6-pin female terminal block 3.5mm | 5 | 5 | 0.1593 | 0.80 | CN41
 |  |  | SUBTOTAL FEMALE: |  |  | 7.75
 |  | === MALE KEFA CONNECTORS (mating plugs) ===
C440847 | KF2EDGK-3.5-2P | KEFA 2-pin male plug 3.5mm | 10 | 10 | 0.2122 | 2.12 | Mate for CN33 + CN42
C440848 | KF2EDGK-3.5-3P | KEFA 3-pin male plug 3.5mm | 55 | 55 | 0.2179 | 11.98 | Mate for CN22-CN32
C440849 | KF2EDGK-3.5-4P | KEFA 4-pin male plug 3.5mm | 30 | 30 | 0.2871 | 8.61 | Mate for CN34-CN39
C440850 | KF2EDGK-3.5-5P | KEFA 5-pin male plug 3.5mm | 5 | 5 | 0.3663 | 1.83 | Mate for CN40
C440851 | KF2EDGK-3.5-6P | KEFA 6-pin male plug 3.5mm | 5 | 5 | 0.5335 | 2.67 | Mate for CN41
 |  |  | SUBTOTAL MALE: |  |  | 27.21
 |  | === TOTAL ===
 |  |  | GRAND TOTAL: |  |  | 72.67
 |  |  | Combined shipping with the JLCPCB PCBA order (LCSC + JLCPCB ship from the same warehouse): |  |  | 0.00 | FREE
 |  | === NOTES ===
 |  |  | R128 is a Bourns PV37W (~$3); any 10k TH trim pot of the same footprint works.
 |  |  | All KEFA connectors are 3.5mm pitch; the male plugs mate with the on-board female terminals.

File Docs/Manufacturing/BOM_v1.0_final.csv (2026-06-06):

No. | Quantity | Comment | Designator | Footprint | Value | Manufacturer Part | Manufacturer | Supplier Part | Supplier | Mounting Style | LCSC Stock
1 | 1 | 10nF | C1 | C0603 | 10nF | 0603B103K500NT | FH | C57112 | LCSC | SMT
2 | 2 | 4.7uF | C3,C4 | C1206 | 4.7uF | 1206B475K500NT | FH | C29823 | LCSC | SMT
3 | 2 | 22uF | C5,C6 | C0805 | 22uF | CL21A226MAQNNNE | SAMSUNG | C45783 | LCSC | SMT
4 | 1 | 100uF | C7 | CAP-TH_BD6.0-P2.50-D0.5-FD | 100uF | KM1E101M0611 | ROQANG | C2873969 | LCSC | DIP
5 | 5 | 100nF | C8,C11,C14,C16,C18 | C0805 | 100nF | CL21B104KCFNNNE | SAMSUNG | C28233 | LCSC | SMT
6 | 1 | 1nF | C9 | C0603 | 1nF | CL10B102KB8NNNC | SAMSUNG | C1588 | LCSC | SMT
7 | 3 | 10uF | C10,C15,C17 | C0805 | 10uF | GRM21BR61H106KE43L | muRata | C440198 | LCSC | SMT
8 | 5 | 10uF | C12,C13,C23,C38,C69 | CAP-SMD_L3.2-W1.6-RD-C7171 | 10uF | TAJA106K016RNJ | Kyocera AVX | C7171 | LCSC | SMT
9 | 44 | 100nF | C19,C21,C22,C24,C25,C26,C27,C28,C29,C30,C31,C32,C34,C36,C37,C39,C41,C42,C44,C45,C54,C58,C60,C62,C63,C64,C65,C66,C67,C68,C70,C71,C72,C73,C74,C75,C76,C77,C78,C79,C80,C81,C82,C83 | C0603 | 100nF | CC0603KRX7R9BB104 | YAGEO | C14663 | LCSC | SMT
10 | 5 | 4.7uF | C20,C47,C48,C49,C57 | C0603 | 4.7uF | CL10A475KO8NNNC | SAMSUNG | C19666 | LCSC | SMT
11 | 3 | 1uF | C35,C40,C43 | C0603 | 1uF | CL10A105KB8NNNC | SAMSUNG | C15849 | LCSC | SMT
12 | 1 | 22nF | C50 | C0603 | 22nF | CL10B223KB8NNNC | SAMSUNG | C21122 | LCSC | SMT
13 | 2 | 6.8nF | C51,C52 | C0603 | 6.8nF | 0603B682K500NT | FH | C1631 | LCSC | SMT
14 | 2 | 33pF | C53,C59 | C0603 | 33pF | CL10C330JB8NNNC | SAMSUNG | C1663 | LCSC | SMT
15 | 2 | 18pF | C55,C56 | C0603 | 18pF | CL10C180JB8NNNC | SAMSUNG | C1647 | LCSC | SMT
16 | 1 | 1nF | C61 | CAP-TH_L6.8-W2.6-P5.08-D0.6-S2.1 | 1nF | CC3D102KC2IEB46U31MF | Dersonic | C2976624 | LCSC | DIP
17 | 1 | 10nF | C84 | C1206 | 10nF | 1206B103K500NT | FH | C1846 | LCSC | SMT
18 | 1 | TF PUSH | CARD1 | TF-SMD_TF-PUSH |  | TF PUSH | SHOU HAN | C393941 | LCSC | SMT
19 | 11 | KF2EDGR-3.5-3P | CN22,CN23,CN24,CN25,CN26,CN27,CN28,CN29,CN30,CN31,CN32 | CONN-TH_3P-P3.50_KF2EDGR-3.5-3P |  | KF2EDGR-3.5-3P | KEFA | C441172 | LCSC | DIP
20 | 2 | KF2EDGR-3.5-2P | CN33,CN42 | CONN-TH_P3.50_KF2EDGR-3.5-2P |  | KF2EDGR-3.5-2P | KEFA | C441171 | LCSC | DIP
21 | 6 | KF2EDGR-3.5-4P | CN34,CN35,CN36,CN37,CN38,CN39 | CONN-TH_4P-P3.50_KF2EDGR-3.5-4P |  | KF2EDGR-3.5-4P | KEFA | C441173 | LCSC | DIP
22 | 1 | KF2EDGR-3.5-5P | CN40 | CONN-TH_5P-P3.50_KF2EDGR-3.5-5P |  | KF2EDGR-3.5-5P | KEFA | C441174 | LCSC | DIP
23 | 1 | KF2EDGR-3.5-6P | CN41 | CONN-TH_6P-P3.50_KF2EDGR-3.5-6P |  | KF2EDGR-3.5-6P | KEFA | C441175 | LCSC | DIP
24 | 1 | SS54 | D1 | SMA_L4.4-W2.8-LS5.4-R-RD |  | SS54 | MDD | C22452 | LCSC | SMT
25 | 2 | SS34 | D2,D3 | SMA_L4.3-W2.6-LS5.2-RD |  | SS34 | MDD | C8678 | LCSC | SMT
26 | 3 | PSM712-LF-T7 | D4,D5,D6 | SOT-23-3_L3.0-W1.7-P0.95-LS2.9-BR |  | PSM712-LF-T7 | PROTEK | C32677 | LCSC | SMT
27 | 1 | 1N4742A | D7 | DO-41_BD2.4-L4.7-P8.70-D0.9-RD |  | 1N4742A | onsemi | C140853 | LCSC | DIP
28 | 1 | PZ254V-11-04P | H1 | HDR-TH_4P-P2.54-V-M |  | PZ254V-11-04P | XFCN | C2691448 | LCSC | DIP
29 | 1 | 22uH | L1 | IND-SMD_L11.6-W10.1 | 22uH | CYA1040-22UH | SHOU HAN | C6364679 | LCSC | SMT
30 | 1 | BLM18PG121SN1D | L2 | L0603 |  | BLM18PG121SN1D | muRata | C14709 | LCSC | SMT
31 | 1 | 3.3uH | L3 | IND-SMD_L2.0-W1.6_AOTA-B201610S3R3-101-T | 3.3uH | AOTA-B201610S3R3-101-T | ABRACON | C42411119 | LCSC | SMT
32 | 6 | KT-0805G | LED1,LED2,LED3,LED4,LED5,LED6 | LED0805-R-RD |  | KT-0805G | KENTO | C2297 | LCSC | SMT
33 | 2 | 2N7002 | Q1,Q2 | SOT-23-3_L2.9-W1.3-P1.90-LS2.4-BR |  | 2N7002 | CJ | C8545 | LCSC | SMT
34 | 2 | 5.1k | R1,R5 | R0603 | 5.1k | 0603WAF5101T5E | UNI-ROYAL | C23186 | LCSC | SMT
35 | 1 | 6.8k | R2 | R0603 | 6.8k | 0603WAF6801T5E | UNI-ROYAL | C23212 | LCSC | SMT
36 | 1 | 1.5k | R3 | R0603 | 1.5k | 0603WAF1501T5E | UNI-ROYAL | C22843 | LCSC | SMT
37 | 37 | 10k | R6,R8,R9,R31,R37,R38,R48,R54,R56,R59,R66,R70,R75,R76,R77,R78,R79,R80,R81,R82,R84,R89,R99,R101,R102,R103,R104,R105,R106,R108,R110,R116,R117,R120,R122,R124,R127 | R0603 | 10k | 0603WAF1002T5E | UNI-ROYAL | C25804 | LCSC | SMT
38 | 2 | 2k | R7,R121 | R0603 | 2k | 0603WAF2001T5E | UNI-ROYAL | C22975 | LCSC | SMT
39 | 7 | 1k | R10,R11,R12,R40,R123,R125,R126 | R0603 | 1k | 0603WAF1001T5E | UNI-ROYAL | C21190 | LCSC | SMT
40 | 2 | 4.7k | R13,R14 | R1206 | 4.7k | 1206W4F4701T5E | UNI-ROYAL | C17936 | LCSC | SMT
41 | 19 | 33R | R15,R41,R43,R44,R47,R49,R52,R57,R61,R62,R65,R67,R72,R85,R87,R90,R93,R94,R97 | R0603 | 33R | 0603WAF330JT5E | UNI-ROYAL | C23140 | LCSC | SMT
42 | 1 | 10R | R16 | R0603 | 10R | 0603WAF100JT5E | UNI-ROYAL | C22859 | LCSC | SMT
43 | 3 | 4.7k | R17,R20,R21 | R0603 | 4.7k | 0603WAF4701T5E | UNI-ROYAL | C23162 | LCSC | SMT
44 | 4 | 49.9R | R18,R19,R26,R27 | R0603 | 49.9R | 0603WAF499JT5E | UNI-ROYAL | C23185 | LCSC | SMT
45 | 4 | 4.7R | R22,R23,R24,R25 | R0603 | 4.7R | 0603WAF470KT5E | UNI-ROYAL | C23164 | LCSC | SMT
46 | 1 | 1M | R28 | R0603 | 1M | 0603WAF1004T5E | UNI-ROYAL | C22935 | LCSC | SMT
47 | 1 | 0R | R29 | R0603 | 0R | 0603WAF0000T5E | UNI-ROYAL | C21189 | LCSC | SMT
48 | 1 | 12.4k | R30 | R0603 | 12.4k | RC0603FR-0712K4L | YAGEO | C137798 | LCSC | SMT
49 | 20 | 330R | R32,R39,R42,R45,R46,R50,R51,R53,R60,R63,R64,R68,R71,R73,R86,R91,R92,R95,R96,R100 | R0603 | 330R | 0603WAF3300T5E | UNI-ROYAL | C23138 | LCSC | SMT
50 | 1 | 1M | R35 | R1206 | 1M | 1206W4F1004T5E | UNI-ROYAL | C17927 | LCSC | SMT
51 | 10 | 5.6k | R55,R58,R69,R74,R83,R88,R98,R107,R109,R112 | R0805 | 5.6k | 0805W8F5601T5E | UNI-ROYAL | C4382 | LCSC | SMT
52 | 2 | 120R | R111,R113 | R0603 | 120R | 0603WAF1200T5E | UNI-ROYAL | C22787 | LCSC | SMT
53 | 2 | 22R | R114,R115 | R0402 | 22R | 0402WGF220JTCE | UNI-ROYAL | C25092 | LCSC | SMT
54 | 1 | 10k trim pot | R128 | RES-ADJ-TH_L6.7-W4.5-P2.50_PV37W | 10k | PV37W103C01B00 | BOURNS | C6630214 | LCSC | DIP
55 | 1 | J1B1211CCD | RJ1 | RJ45-TH_J1B1211CCD |  | J1B1211CCD | WIZNET | C910371 | LCSC | DIP
56 | 2 | TS-1088-AR02016 | SW1,SW2 | SW-SMD_L3.9-W3.0-P4.45 |  | TS-1088-AR02016 | XUNPU | C720477 | LCSC | SMT
57 | 1 | TPS5430DDAR | U1 | ESOP-8_L4.9-W3.9-P1.27-LS6.0-TL-EP |  | TPS5430DDAR | TI | C9864 | LCSC | SMT
58 | 1 | AMS1117-3.3 | U2 | SOT-223-3_L6.5-W3.4-P2.30-LS7.0-BR |  | AMS1117-3.3 | AMS | C6186 | LCSC | SMT
59 | 1 | B2424S-2WR3 | U3 | PWRM-TH_BXXXXS-2WR3 | 100kHz | B2424S-2WR3 | YLPTEC | C5369487 | LCSC | DIP
60 | 1 | RP2350B | U4 | QFN-80_L10.0-W10.0-P0.40-TL-EP3.4 |  | RP2350B | Raspberry Pi | C42415655 | LCSC | SMT
61 | 1 | W5500 | U5 | LQFP-48_L7.0-W7.0-P0.50-LS9.0-BL |  | W5500 | WIZNET | C32843 | LCSC | SMT
62 | 1 | W25Q128JVSIQ | U6 | SOIC-8_L5.3-W5.3-P1.27-LS8.0-BL |  | W25Q128JVSIQ | Winbond | C97521 | LCSC | SMT
63 | 3 | 74HC14D,653 | U7,U10,U15 | SOIC-14_L8.7-W3.9-P1.27-LS6.0-BL |  | 74HC14D,653 | Nexperia | C5605 | LCSC | SMT
64 | 10 | LTV-217-B-G | U8,U9,U11,U12,U13,U14,U16,U17,U18,U20 | SOP-4_L4.4-W2.8-P1.27-LS7.0-BR |  | LTV-217-B-G | LITEON | C115450 | LCSC | SMT
65 | 3 | SP3485EN-L/TR | U19,U21,U22 | SOIC-8_L5.0-W4.0-P1.27-LS6.0-BL |  | SP3485EN-L/TR | MaxLinear | C8963 | LCSC | SMT
66 | 1 | LM358DR2G | U23 | SOIC-8_L5.0-W4.0-P1.27-LS6.0-BL |  | LM358DR2G | onsemi | C7950 | LCSC | SMT
67 | 1 | TYPE-C-31-M-12 | USBC1 | USB-C_SMD-TYPE-C-31-M-12_1 |  | TYPE-C-31-M-12 | Korean Hanyong | C165948 | LCSC | SMT
68 | 1 | 25MHz | X1 | CRYSTAL-SMD_4P-L3.2-W2.5-BL | 25MHz | X322525MOB4SI | YXC | C9006 | LCSC | SMT
69 | 1 | 12MHz | X2 | CRYSTAL-SMD_4P-L3.2-W2.5-BL | 12MHz | X322512MSB4SI | YXC | C9002 | LCSC | SMT

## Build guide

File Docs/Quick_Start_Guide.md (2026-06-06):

# RectaBot v1.0 — Quick Start Guide

**From an unboxed board to the first motor movement — step by step.**

Estimated time: **2-3 hours** (including soldering 28 TH components).

---

## 📦 What's in the box

### From the JLCPCB package (DHL Express DDP)
- ✅ **5× RectaBot v1.0 PCB** with SMT-mounted components
- ✅ ENIG gold finish (durable, great for soldering)
- ❌ **NO Through-Hole components** (customs reasons)
- 📄 JLCPCB packaging + invoice

### From the LCSC package (FedEx International Priority)
- ✅ **28 TH components × 5 sets** + MOQ extras
  - Detailed list: [Hand_Solder_Components.md](Hand_Solder_Components.md)
- ✅ **Male KEFA connectors** (KF2EDGK series) for screw terminals
- 📄 LCSC invoice (keep for customs!)

### What YOU need to provide (not in the package)

| Tool / Material | Details |
|---|---|
| **Soldering iron** | TS100 / Pinecil / Hakko FX-888D, set to 320-350°C |
| **Solder** | 60/40 Sn/Pb 0.6-0.8mm with rosin core |
| **Multimeter** | Any digital one with continuity and voltage modes |
| **Tweezers** | ESD-safe, for holding TH components during soldering |
| **Loupe / microscope** | Useful for visual QFN-80 RP2350B inspection before power-on |
| **24V DC power supply** | 24V / 2A min, e.g. Mean Well RS-50-24 or screw-terminal adapter |
| **USB-C cable** | Data + power, for firmware flash and debug |
| **Test pins / Dupont cables** | For probing rails |

---

## 🔍 Step 1: Visual inspection (10 min)

**Before you solder anything:**

### 1a. Top side check
Place the PCB under a loupe/microscope and verify:

- ✅ All QFN-80 (RP2350B) pads have a clean ENIG finish (no oxidation)
- ✅ The W5500 QFN and SP3485 SOIC-8 packages are correctly oriented (pin 1 marker = bottom-left)
- ✅ No **solder bridges** between adjacent RP2350B pins (the biggest risk)
- ✅ LM358 (U23), 2N7002 (Q1/Q2) are in place
- ✅ All LEDs (LED1-LED6, marked KT-0805G in BOM) are present and correctly oriented
- ✅ The TF (microSD) connector is well soldered and clicks via its push-push mechanism

### 1b. Bottom side check
- ✅ R36 and C33 are DNP (Do Not Populate) and are NOT present on the bottom — that's expected
- ✅ No visible PCB damage (scratches, exposed traces)

### 1c. What to do if you find a problem
- **Solder bridge** → rework with flux + braid
- **Cold joint** (matte, lumpy surface) → resolder with fresh flux
- **Misaligned IC** → reflow with hot air (300°C, 30s)
- **PCB damage / tear** → contact JLCPCB support with photos

---

## 🔧 Step 2: Hand-soldering TH components (60-90 min)

**Follow the order from [Hand_Solder_Components.md](Hand_Solder_Components.md):**

### Phase A: Lowest-profile components first
1. **D7** Zener 1N4742A — `cathode (band) must face the SPIN_10V net`
2. **R128** PV37W trim pot — orientation doesn't matter
3. **H1** SWD header — straight, 4-pin

### Phase B: Medium-height components
4. **C7** 100µF electrolytic — **POLARITY CRITICAL** — positive lead (longer) to +5V
5. **C61** 1nF/2kV ceramic chassis cap — Bob Smith capacitor

### Phase C: Taller components
6. **U3** B2424S-2WR3 — isolated DC/DC, 4-pin SIP
7. **RJ1** RJ45 J1B1211CCD — watch the shield pins (chassis ground)

### Phase D: Connectors (tallest, last)
8. **CN22-CN42** screw terminals (KEFA KF2EDGR)
   - Pin 1 of each connector aligns with the **PCB silkscreen marker** (a thicker line or square)
   - Short but strong solder joints — TH connectors take mechanical stress

### ⚠️ Polarities you MUST remember
| Component | Polarity info |
|---|---|
| **D7 1N4742A** | The cathode (black band) goes to **SPIN_10V**. Reversed = no overvoltage protection. |
| **C7 100µF** | Positive lead (longer) to the **+5V** side. Reversed = **explosion on first power-on!** |
| **U3 B2424S** | Pin 1 has a silkscreen dot — orient it to match the PCB silkscreen |
| **RJ1 RJ45** | Correctly oriented = LEDs face the PCB edge (outward) |

---

## 🧪 Step 3: Pre-power-on check (15 min)

**MANDATORY — do this BEFORE you connect 24V power!**

See [First_Power_On_Procedure.md](First_Power_On_Procedure.md) for the detailed procedure.

**Summary:**
1. Multimeter on continuity mode
2. Verify there are NO shorts:
   - 24V → GND (probe CN42 pin 1 and 2)
   - +5V → GND
   - +3.3V → GND
   - 24V_ISO → GND_ISO
3. Visually re-check the electrolytic polarity (C7) one more time

---

## ⚡ Step 4: First power-on (10 min)

**Detailed procedure with expected measurements:** [First_Power_On_Procedure.md](First_Power_On_Procedure.md)

**Summary:**

1. **Connect 24V** to CN42 (pin 1 = +24V, pin 2 = GND)
2. **Watch the LEDs:**
   - 24V power LED → lit ✅
   - 5V power LED → lit ✅
   - 3V3 power LED → lit ✅
   - 24V_ISO power LED → lit ✅
3. **Measure with the multimeter:**
   - +5V rail = 4.95 - 5.05V ✅
   - +3.3V rail = 3.25 - 3.35V ✅
   - +24V_ISO rail = 23.5 - 24.5V ✅
4. **NO SMOKE**, no crackling sounds, no overheating components

**If anything is off** → power down immediately and check the troubleshooting section in First_Power_On_Procedure.md.

---

## 💾 Step 5: Firmware flash (15 min)

### 5a. Enter BOOTSEL mode
1. Press and hold the **BOOT button** on the PCB
2. While holding BOOT, press and release the **RESET button**
3. Release the BOOT button
4. The RP2350B will enumerate as a **USB Mass Storage** device (drive `RPI-RP2`)

### 5b. Flash grblHAL firmware
1. Connect a USB-C cable PC ↔ RectaBot
2. Open `RPI-RP2` in Explorer
3. Drag-and-drop **`grblHAL_RectaBot_v1.0.uf2`** into the drive
4. The drive disappears and the RP2350B reboots into grblHAL

### 5c. Verify the firmware
1. Open a serial monitor (PuTTY / Arduino IDE Serial Monitor / minicom)
2. Connect to the COM port (115200 baud, 8N1)
3. You should see:
   ```
   GrblHAL 1.1f ['$' for help]
   [VER:1.1f.20260101:RectaBot v1.0]
   [OPT:VNMSL,35,1024,16,7]
   ```

---

## ⚙️ Step 6: grblHAL configuration (20 min)

**Critical parameters for RectaBot v1.0:**

```
$0=10        ; Step pulse, microseconds
$1=25        ; Step idle delay, milliseconds
$2=31        ; Step pulse invert, mask (CRITICAL for 74HC14D)
$3=31        ; Step direction invert, mask (CRITICAL for 74HC14D)
$4=1         ; Invert step enable pin (CRITICAL for 74HC14D)
$5=0         ; Invert limit pins, boolean
$6=0         ; Invert probe pin
$10=1        ; Status report options, mask
$11=0.010    ; Junction deviation, millimeters
$12=0.002    ; Arc tolerance, millimeters
$13=0        ; Report in inches, boolean
$20=0        ; Soft limits enable, boolean
$21=1        ; Hard limits enable, boolean
$22=1        ; Homing cycle enable, boolean
$23=3        ; Homing direction invert, mask
$24=25.000   ; Homing locate feed rate, mm/min
$25=500.000  ; Homing search seek rate, mm/min
$26=250      ; Homing switch debounce delay, milliseconds
$27=1.000    ; Homing switch pull-off distance, millimeters
$30=24000    ; Maximum spindle speed, RPM (for a 24kRPM VFD)
$31=0        ; Minimum spindle speed, RPM
$32=0        ; Laser-mode enable, boolean (leave 0 for spindle)
```

**Per-axis configuration** (X axis shown, same for Y/Z/A/B):
```
$100=80.000  ; X-axis steps per millimeter (depends on the driver)
$110=2000.000 ; X-axis maximum rate, mm/min
$120=200.000  ; X-axis acceleration, mm/sec²
$130=300.000  ; X-axis maximum travel, millimeters
```

---

## 🎮 Step 7: First axis test (10 min)

### 7a. Connect a DM556 driver to CN34 (X axis)
- Pin 1 = STEP_X_5V → DM556 PUL+
- Pin 2 = DIR_X_5V → DM556 DIR+
- Pin 3 = EN_X_5V → DM556 ENA+
- Pin 4 = GND → DM556 PUL-, DIR-, ENA- (common cathode, all to GND)

**Note:** the DM556 +5V (common PUL+, DIR+, ENA+) goes to the **+5V rail**, NOT to pin 4 GND!

### 7b. Connect a motor to the DM556 outputs
- A+, A-, B+, B- (4-wire NEMA17/23 motor)
- Set the DM556 microstep DIP switches (e.g. 1600 steps/rev for 8 microsteps)

### 7c. Try a jog command in the serial monitor
```
$J=G91 X10 F500    ; Move 10mm to the right @ 500mm/min
$J=G91 X-10 F500   ; Move 10mm to the left
```

**What to expect:**
- ✅ The motor turns smoothly, without "skipping"
- ✅ Direction follows the DIR command
- ✅ It stops at the position
- ❌ If it jitters or doesn't move → see troubleshooting

---

## 🎯 Next steps

Once the X axis runs reliably:
1. **Repeat for Y, Z, A, B** (CN35-CN38)
2. **Connect limit switches** (CN27-CN31)
3. **Configure homing** (`$H` command)
4. **Connect the VFD** — see [VFD_Wiring_Guide.md](VFD_Wiring_Guide.md)
5. **Test G-code execution** with a sender (UGS, CNCjs, IO Sender)

---

## 🆘 Troubleshooting

### Power rails out of spec
- **+5V < 4.9V** → TPS5430 buck may have a cold joint on L1 or the VSENSE divider
- **+3.3V < 3.2V** → AMS1117 LDO overloaded or poorly soldered
- **+24V_ISO < 23V** → B2424S DC/DC not working or 24V_IN too low

### LEDs don't light up
- **All LEDs off** → 24V isn't reaching the board (check CN42 polarity!)
- **Only the 24V LED is lit** → TPS5430 problem
- **24V + 5V LEDs lit, 3V3 off** → AMS1117 problem

### USB enumeration doesn't work
- **Drive does not appear** → wrong BOOT/RESET sequence, repeat it
- **Drive appears, then immediately disappears** → firmware file corrupted or wrong UF2

### Motor doesn't move
- **0 pulses on STEP pin** → grblHAL $2 isn't set to 31 (INVERT_MASK)
- **Constant HIGH on STEP** → 74HC14D not soldered properly
- **Motor "skips"** → microstep DIP switches don't match the $100 parameter

---

## 📚 Further reading

- [Pinout.md](Pinout.md) — complete GPIO map
- [Hardware_Design_Guidelines.md](Hardware_Design_Guidelines.md) — electrical and mechanical design
- [VFD_Wiring_Guide.md](VFD_Wiring_Guide.md) — how to wire various VFDs
- [Product_Specification_v1.0.md](Product_Specification_v1.0.md) — complete datasheet

---

*Need help? Open an issue on GitHub or email hello@rectabot.org*

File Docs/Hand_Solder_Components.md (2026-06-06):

# RectaBot v1.0 — Hand-Soldered Components Reference

**Components YOU solder by hand after receiving the board from JLCPCB.**

⚠️ **IMPORTANT:** JLCPCB **DOES NOT SHIP** these components — all TH parts must be ordered separately from LCSC.
Confirmed via JLCPCB chat (Desmond, 04.06.2026):
> "If you didn't select them to be assembled at the ordering page, we will not charge them and hence we will not send them to you."

See: [LCSC_Additional_Order.csv](LCSC_Additional_Order.csv) for the full list with LCSC codes.

---

## 📦 Component list (by designator)

| # | Designator | Value | Footprint | LCSC | Mounting |
|---|---|---|---|---|---|
| 1 | **C7** | 100µF electrolytic | TH BD6.0-P2.50 | C2873969 | Vertical, watch polarity (-/+ on silkscreen) |
| 2 | **C61** | 1nF / 2kV ceramic | TH L6.8-W2.6-P5.08 | C2976624 | Bob Smith chassis coupling |
| 3 | **CN22** | KF2EDGR-3.5-3P | TH 3-pin | C441172 | RS485 Modbus |
| 4 | **CN23** | KF2EDGR-3.5-3P | TH 3-pin | C441172 | FEED HOLD input |
| 5 | **CN24** | KF2EDGR-3.5-3P | TH 3-pin | C441172 | CYCLE START input |
| 6 | **CN25** | KF2EDGR-3.5-3P | TH 3-pin | C441172 | PROBE input |
| 7 | **CN26** | KF2EDGR-3.5-3P | TH 3-pin | C441172 | ESTOP input |
| 8 | **CN27** | KF2EDGR-3.5-3P | TH 3-pin | C441172 | B_LIMIT input |
| 9 | **CN28** | KF2EDGR-3.5-3P | TH 3-pin | C441172 | A_LIMIT input |
| 10 | **CN29** | KF2EDGR-3.5-3P | TH 3-pin | C441172 | Z_LIMIT input |
| 11 | **CN30** | KF2EDGR-3.5-3P | TH 3-pin | C441172 | Y_LIMIT input |
| 12 | **CN31** | KF2EDGR-3.5-3P | TH 3-pin | C441172 | X_LIMIT input |
| 13 | **CN32** | KF2EDGR-3.5-3P | TH 3-pin | C441172 | DOOR input |
| 14 | **CN33** | KF2EDGR-3.5-2P | TH 2-pin | C441171 | Laser PWM / GND |
| 15 | **CN42** | KF2EDGR-3.5-2P | TH 2-pin | C441171 | 24V DC INPUT |
| 16 | **CN34** | KF2EDGR-3.5-4P | TH 4-pin | C441173 | X Stepper (STEP/DIR/EN/GND) |
| 17 | **CN35** | KF2EDGR-3.5-4P | TH 4-pin | C441173 | Y Stepper |
| 18 | **CN36** | KF2EDGR-3.5-4P | TH 4-pin | C441173 | Z Stepper |
| 19 | **CN37** | KF2EDGR-3.5-4P | TH 4-pin | C441173 | A Stepper |
| 20 | **CN38** | KF2EDGR-3.5-4P | TH 4-pin | C441173 | B Stepper (Y2 tandem) |
| 21 | **CN39** | KF2EDGR-3.5-4P | TH 4-pin | C441173 | Spindle VFD (10V/EN/DIR/GND) |
| 22 | **CN40** | KF2EDGR-3.5-5P | TH 5-pin | C441174 | AUX (5V/VAC/FLOOD/MIST/GND) |
| 23 | **CN41** | KF2EDGR-3.5-6P | TH 6-pin | C441175 | RS422 Pendant (24V/TX+/TX-/RX+/RX-/GND) |
| 24 | **D7** | 1N4742A Zener 12V | TH DO-41 | C140853 | Watch the cathode (band) — it faces the SPIN_10V net |
| 25 | **H1** | PZ254V-11-04P | TH 4-pin 2.54mm | C2691448 | SWD debug header |
| 26 | **R128** | PV37W103C01B00 trim pot 10k | TH PV37W | C6630214 | Spindle 0-10V gain calibration |
| 27 | **RJ1** | J1B1211CCD | TH RJ45 | C910371 | Ethernet with integrated magnetics |
| 28 | **U3** | B2424S-2WR3 | TH 4-pin DC/DC | C5369487 | Isolated 24V→24V_ISO for opto LEDs |

**Total: 28 components for hand-soldering (all come with the JLCPCB board)**

---

## 🛠️ Soldering order (recommended)

### Phase 1: Lowest-profile components first
1. **D7** Zener (bend the leads into a "P" shape for stress relief)
2. **R128** trim pot
3. **H1** SWD header

### Phase 2: Medium height
4. **C7** electrolytic (polarity! shorter lead = minus)
5. **C61** ceramic chassis cap

### Phase 3: Taller components
6. **U3** B2424S DC/DC module
7. **RJ1** RJ45 connector (careful with the shield pins)

### Phase 4: Connectors (tallest)
8. All **CN22-CN42** screw terminals (KEFA)

### Phase 5: Verification
- Visual inspection of solder joints
- Continuity test with the multimeter (GND to main pins)
- Power-on test without main components connected

---

## ⚠️ Specific notes

### **D7 1N4742A Zener — polarity CRITICAL**
- The cathode (band on the body) faces **SPIN_10V** (output signal)
- The anode (no band) goes to **GND**
- If reversed → the Zener never conducts → no VFD protection

### **C7 100µF electrolytic — polarity CRITICAL**
- The positive lead (longer) faces the **+5V** side
- The negative lead (shorter, white band on the can) faces **GND**
- If reversed → explosion on first power-on!

### **RJ1 RJ45 — watch the shield pins**
- It has 2 extra pins for chassis ground/shield
- They must be soldered for EMI performance
- Bob Smith termination works only if the shield is connected

### **R128 trim pot — calibration**
- After soldering: connect the VFD and tune so that at max PWM you get exactly 10.0V
- See [VFD_Wiring_Guide.md](VFD_Wiring_Guide.md) for details

---

## 📋 What YOU must purchase separately (NOT in the JLCPCB package)

**ALL components on this list (28 TH parts) + male KEFA mating connectors.**

See: [LCSC_Additional_Order.csv](LCSC_Additional_Order.csv) — full BOM for 5 boards (~$50 with male connectors).

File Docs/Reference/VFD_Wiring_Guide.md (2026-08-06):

# RectaBot — VFD Wiring & Configuration Guide

**Version:** 1.0 | **Hardware:** RectaBot v1.0 | **Firmware:** grblHAL

This guide explains how to connect and configure popular Variable Frequency Drives (VFDs) to the RectaBot CNC controller for spindle control.

It covers **analog** control: a 0-10 V speed reference plus enable/direction lines on
CN39. If your VFD has an RS-485 port, digital control is the better option — exact
speeds and real feedback from the drive — see
[VFD_Modbus_Setup.md](VFD_Modbus_Setup.md).

---

## 📐 CN39 Spindle Connector Pinout

RectaBot uses a 4-pin **CN39** connector (3.5mm pitch screw terminal) for spindle control:

| Pin | Net Name | Function | Signal Type | Typical VFD Terminal |
|---|---|---|---|---|
| **1** | `VFD_10V` | Analog speed reference | 0-10V DC | VI, AVI, AI1, AIN1, FV |
| **2** | `VFD_EN` | Run / Enable | Active LOW open-drain | FWD, FOR, X1, DI1, RUN |
| **3** | `VFD_DIR` | Direction select | Active LOW open-drain | REV, X2, DI2, DIR |
| **4** | `GND` | Signal & analog ground | 0V reference | GND, ACM, COM, DCM |

### ⚠️ Critical compatibility note

The **VFD_EN** and **VFD_DIR** pins use **2N7002 N-MOSFET open-drain output**. This means:
- When MCU asserts HIGH → MOSFET pulls pin to GND (active LOW)
- When MCU asserts LOW → MOSFET is OFF, pin is high-impedance (floating)

**Compatible VFD input types:**
- ✅ **NPN sinking inputs** (most Chinese VFDs: Huanyang, Lapond, Delta) — works directly
- ⚠️ **PNP sourcing inputs** (most industrial: Siemens, ABB, Schneider) — needs external relay module
- ✅ **Dry contact inputs** — works directly

**Maximum voltage tolerance on VFD_EN / VFD_DIR pins: 60V** (2N7002 Vds rating). Safe for any VFD with up to 48V digital input voltage.

---

## 🔌 1. Huanyang HY01 / HY02 (Most Common, ~50% of Hobby Market)

**Examples:** HY01-D751 (0.75kW), HY02-D152 (1.5kW), HY02-D222 (2.2kW)

### Wiring

```
RectaBot CN39                Huanyang VFD (HY01/HY02)
─────────────                ──────────────────────────
Pin 1  VFD_10V  ──────────►  VI    (analog speed input)
Pin 2  VFD_EN   ──────────►  FOR   (forward run terminal)
Pin 3  VFD_DIR  ──────────►  REV   (reverse run terminal)
Pin 4  GND      ─────┬────►  ACM   (analog common)
                     └────►  DCM   (digital common, jumper to ACM)
```

**Cable:** Use **shielded twisted pair** for VFD_10V + ACM. Connect cable shield to VFD chassis ground on one end only.

### Parameter Configuration

Enter VFD programming mode (PRG button), then set these parameters:

| Parameter | Value | Description |
|---|---|---|
| `PD001` | `1` | Run command source = external terminals |
| `PD002` | `1` | Frequency reference = external AVI (0-10V analog) |
| `PD003` | `400` | Main frequency (Hz) — adjust to your spindle's rated frequency |
| `PD004` | `400` | Base frequency (typically same as PD003) |
| `PD005` | `400` | Max output frequency (Hz) |
| `PD006` | `2.5` | Intermediate frequency for V/f curve |
| `PD007` | `0.5` | Min output frequency |
| `PD008` | `220` | Max voltage (V) — match your motor's rated voltage |
| `PD009` | `15` | Intermediate voltage |
| `PD010` | `8` | Min voltage |
| `PD011` | `120` | Frequency lower limit (Hz) — minimum spindle RPM |
| `PD014` | `5.0` | Acceleration time (s) |
| `PD015` | `5.0` | Deceleration time (s) |
| `PD044` | `1` | **Two-line mode 1** — FOR=RUN, REV=DIRECTION (CRITICAL!) |
| `PD045` | `0` | Disable jog terminals |
| `PD070` | `1` | Analog input 0-10V mode |
| `PD072` | `400` | Analog input max frequency |

### grblHAL Configuration

After flashing RectaBot firmware, set these via UART/USB (`$$` to view all settings):

```
$30=24000          ; Max spindle RPM (must match VFD PD005 × 60 / motor_poles)
$31=0              ; Min spindle RPM
$32=0              ; Laser mode disabled (we're using spindle)
```

### Test Procedure

1. Power on RectaBot, connect VFD per wiring diagram above
2. Power on VFD, verify display shows "0.0Hz" idle
3. Send G-code: `M3 S12000` (spindle on, forward, 12000 RPM)
4. Multimeter on CN39 pin 1 (VFD_10V) should read ~5V (50% of max)
5. VFD display should show ~200Hz (50% of 400Hz max)
6. Spindle should rotate clockwise (CW) at 12000 RPM
7. Send `M5` to stop
8. Send `M4 S12000` to test reverse — spindle should rotate counter-clockwise (CCW)

### Troubleshooting

| Symptom | Cause | Solution |
|---|---|---|
| Spindle doesn't start | PD001 wrong | Set PD001=1 (terminal control) |
| Speed control doesn't work | PD002 wrong | Set PD002=1 (AVI analog) |
| M4 (reverse) doesn't work | PD044 wrong | Set PD044=1 (two-line mode 1) |
| Spindle runs at wrong speed | Calibration | Adjust trim pot R128 on RectaBot until 100% PWM = 10.0V exactly |
| VFD alarm "ESC" | Both FOR+REV active | Check PD044=1 (NOT PD044=0) |

---

## 🔌 2. Lapond SVD-EM (~15% of market)

**Examples:** SVD-EM 7.5G/11P 4T, SVD-EM 0.75G 4T

### Wiring

```
RectaBot CN39                Lapond SVD-EM
─────────────                ──────────────────────
Pin 1  VFD_10V  ──────────►  AI1   (analog input 1)
Pin 2  VFD_EN   ──────────►  DI1   (digital input 1)
Pin 3  VFD_DIR  ──────────►  DI2   (digital input 2)
Pin 4  GND      ─────┬────►  GND   (analog ground)
                     └────►  COM   (digital common — jumper to GND)
```

### Parameter Configuration

| Parameter | Value | Description |
|---|---|---|
| `F1.00` | `1` | Run command source = terminal control |
| `F1.01` | `0` | Two-line mode (DI1=RUN, DI2=DIR) |
| `F1.06` | `2` | Speed source = analog AI1 |
| `F1.07` | `0` | DI1 function = Run/Stop |
| `F1.08` | `2` | DI2 function = Forward/Reverse direction |
| `F2.00` | `0` | AI1 input range = 0-10V |
| `F2.01` | `0.0` | AI1 minimum voltage |
| `F2.02` | `10.0` | AI1 maximum voltage |
| `F3.00` | `400` | Max output frequency (Hz) |
| `F3.05` | `5.0` | Acceleration time (s) |
| `F3.06` | `5.0` | Deceleration time (s) |

### Notes
- Lapond uses **F-group parameters** (F1.xx, F2.xx, F3.xx) instead of PD-style
- Default password to enter programming: `0000` or `1234`
- After config, save with **STORE** or **ENT** button

---

## 🔌 3. Delta VFD-M / VFD-EL (~10% of market)

**Examples:** VFD007M21A (0.75kW), VFD015M23A (1.5kW), VFD022EL43A (2.2kW)

### Wiring

```
RectaBot CN39                Delta VFD-M/EL
─────────────                ──────────────────────
Pin 1  VFD_10V  ──────────►  AVI   (analog voltage input)
Pin 2  VFD_EN   ──────────►  M0    (multi-function input 0)
Pin 3  VFD_DIR  ──────────►  M1    (multi-function input 1)
Pin 4  GND      ─────┬────►  ACM   (analog common)
                     └────►  DCM   (digital common — jumper to ACM)
```

### Parameter Configuration

| Parameter | Value | Description |
|---|---|---|
| `02-00` | `1` | Frequency source = external analog AVI |
| `02-01` | `1` | Operation command = external terminals |
| `02-05` | `0` | AVI input = 0-10V (not 4-20mA) |
| `04-04` | `1` | Two-wire / three-wire mode = **Two-wire 1** |
| `04-05` | `0` | Two-wire type 1: M0=RUN, M1=DIRECTION |
| `04-11` | `1` | M0 function = Forward/Reverse run |
| `04-12` | `0` | M1 function = Direction select |
| `01-00` | `400.0` | Max output frequency (Hz) |
| `01-09` | `5.0` | Acceleration time (s) |
| `01-10` | `5.0` | Deceleration time (s) |

### Notes
- Delta uses **two-digit group.member** parameter format (e.g., `02-00`)
- Access programming mode: **MODE** button → enter password if set
- After parameter change: **ENTER** to save, then **MODE** to exit

---

## 🔌 4. Generic NPN Sinking VFD (ATO, Yiqi, Tecorp, Powtran)

If your VFD is not listed above but supports **NPN sinking digital inputs**, use this generic config:

### Wiring (universal)

```
RectaBot CN39                Generic VFD
─────────────                ──────────────────────
Pin 1  VFD_10V  ──────────►  Analog voltage input (VI / AVI / AI1 / 10V)
Pin 2  VFD_EN   ──────────►  Run terminal (FWD / RUN / X1 / DI1)
Pin 3  VFD_DIR  ──────────►  Direction terminal (REV / DIR / X2 / DI2)
Pin 4  GND      ─────┬────►  Analog ground (GND / ACM / AGND)
                     └────►  Digital common (DCM / COM / SC — jumper to GND)
```

### Required VFD Settings (translate to your manual's parameter names)

1. **Run command source** = external terminals (not keypad)
2. **Frequency reference source** = external analog voltage 0-10V
3. **Control mode** = **Two-wire mode 1** (RUN + DIRECTION semantic)
   - NOT "Two-wire mode 2" (which uses FOR + REV semantic — incompatible without firmware patch)
4. **Digital input logic** = NPN sinking (negative logic)
5. **Analog input range** = 0-10V (not 4-20mA, not 2-10V)

---

## 🔌 5. PNP Sourcing / Industrial VFDs (Siemens, ABB, Schneider)

⚠️ **RectaBot's open-drain output cannot directly drive PNP sourcing inputs.** You need an **external 2-channel relay module** ($3-5 on AliExpress).

### Recommended Relay Module

Search AliExpress / Aliexpress for: **"2 channel 3.3V relay module optocoupler"**

Look for these features:
- 3.3V trigger compatible
- Optocoupler isolation
- 10A 250VAC contact rating (more than enough)
- LED indicators per channel

### Wiring with Relay Module

```
RectaBot CN39          Relay Module          PNP Sourcing VFD
─────────────          ────────────          ─────────────────
Pin 1  VFD_10V ──────────────────────────────► AI1 (0-10V analog)
Pin 2  VFD_EN  ────────► IN1 (3.3V trigger)
Pin 3  VFD_DIR ────────► IN2
Pin 4  GND     ────────► GND
                         +5V ←── from RectaBot +5V test point or USB
                                              ┌──────────────────┐
                         NO1 ─────────────────► DI1 (RUN)        │
                         COM1 ────────────────► +24V (VFD source)│
                         NO2 ─────────────────► DI2 (DIR)        │
                         COM2 ────────────────► +24V (VFD source)│
                                              └──────────────────┘
```

The relay's **dry contact (NO + COM)** bridges the VFD's +24V supply to its DI inputs when MCU asserts the corresponding signal — perfectly matching PNP sourcing behavior.

### Future RectaBot v2 "Pro" Tier

v2 will integrate **2× Omron G6K-2P-Y relays** directly on the board, eliminating the need for an external module. Industrial customers will get full plug-and-play compatibility with Siemens, ABB, Schneider VFDs out-of-the-box.

---

## 🛠️ Calibration Procedure (One-time Setup)

After connecting any VFD, calibrate the 0-10V converter:

1. Connect **multimeter** to CN39 pin 1 (VFD_10V) and pin 4 (GND)
2. Set multimeter to DC voltage, 20V range
3. In grblHAL console, send: `M3 S<MAX_RPM>` (e.g., `M3 S24000` for 24000 RPM max)
4. Read multimeter — should show close to 10.0V
5. **Adjust trim pot R128** on RectaBot (on top of PCB, labeled "SPIN_TRIM"):
   - Turn clockwise → higher voltage
   - Turn counter-clockwise → lower voltage
6. Repeat until multimeter reads exactly **10.00V at S<MAX_RPM>**
7. Send `M5` to stop, verify multimeter reads ~0V
8. Test mid-range: `M3 S<MAX_RPM/2>` should give ~5.0V

This calibration accounts for PWM source variation (3.2V vs 3.3V from MCU) and resistor tolerance. Do this **once** after first power-up; trim setting holds permanently.

---

## ⚡ Safety Notes

### E-Stop Behavior

When ESTOP is triggered (**CN26**, or a grblHAL alarm):
1. MCU immediately sets GP27 PWM = 0%, GP30/31 = LOW
2. VFD_10V drops to 0V within 10ms
3. VFD_EN and VFD_DIR go to floating (inactive)
4. **VFD decelerates spindle per its programmed deceleration time** (typically 5s)

⚠️ For **HARD STOP** (no deceleration), you must wire an external safety relay that cuts motor power directly. RectaBot does not provide this — it's an industry-standard external safety device (e.g., Pilz PNOZ, Phoenix EMD, or simple contactor with auxiliary contact).

### Spindle Direction Change

Many VFDs **require spindle to be stopped before changing direction** to prevent mechanical damage. grblHAL handles this automatically — never send M3 → M4 without M5 in between.

### Cable Specifications

| Signal | Recommended Cable | Max Length |
|---|---|---|
| VFD_10V + GND | Shielded twisted pair, 22-24 AWG | 3 meters |
| VFD_EN + VFD_DIR | Standard hookup wire, 22-24 AWG | 3 meters |
| Combined cable | 4-core shielded (e.g., Belden 9534) | 3 meters |

For longer runs (>3m), use **shielded multi-conductor cable** and ground the shield only at the **VFD chassis** end (single-point grounding to prevent ground loops).

---

## 📋 Quick Reference Card

```
┌─────────────────────────────────────────────────────────┐
│  RectaBot CN39 → VFD Quick Wiring                       │
├─────────────────────────────────────────────────────────┤
│  Pin 1  VFD_10V  → Analog speed input (0-10V)           │
│  Pin 2  VFD_EN   → Run command (active LOW)             │
│  Pin 3  VFD_DIR  → Direction (active LOW)               │
│  Pin 4  GND      → Analog + digital ground              │
├─────────────────────────────────────────────────────────┤
│  VFD MUST be in "Two-line mode 1" (RUN/DIR semantic)    │
│  Calibrate trim pot R128 for 10.0V at max RPM           │
│  Use external 2-ch relay for PNP/industrial VFDs        │
└─────────────────────────────────────────────────────────┘
```

---

## 🆘 Support

For issues with specific VFD models not listed here, or custom configurations:

- **Documentation:** https://github.com/rectabot
- **Discord:** RectaBot Users community (planned)
- **Email:** hello@rectabot.org

**When asking for help, please include:**
1. VFD make and model
2. VFD parameter settings (PD001, PD002, etc.)
3. Multimeter readings at CN39 pins during M3/M5 commands
4. grblHAL `$$` output (settings dump)
5. Photo of wiring

---

*Document version 1.0 — last updated for RectaBot v1.0 hardware (firmware: grblHAL with my_machine_map.h).*

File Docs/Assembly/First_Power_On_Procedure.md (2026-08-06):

# RectaBot v1.0 — First Power-On Procedure

**Safely powering up the board for the first time — with a multimeter in hand.**

Estimated time: **15-30 min** (carefully, no rush).

> ⚠️ **WARNING:** This is the riskiest moment of the entire process. A mistake here can destroy a $77 board. Go **slowly** and follow every step.

---

## 🎯 Purpose of this document

1. **Detect critical mistakes** (short circuits, wrong polarities) BEFORE current flows through the PCB
2. **Verify all voltages** after power-on
3. **Establish a baseline** for future troubleshooting

---

## 🛡️ Step 1: Pre-power continuity tests

**Multimeter in Continuity mode (with the buzzer).**

### 1a. Power rail short-circuit tests

Place the multimeter probes between the following points and verify that there is **NO continuity** (no beep):

| Test point 1 | Test point 2 | Expected | What a beep means |
|---|---|---|---|
| **CN42 pin 1** (+24V) | **CN42 pin 2** (GND) | NO continuity | 24V short → do not power on! |
| **+5V rail** (USB-C VBUS pin) | **GND** (USB-C shell) | NO continuity | 5V short → TPS5430 problem |
| **+3.3V rail** (RP2350 pin 3) | **GND** | NO continuity | 3.3V short → AMS1117 or MCU pad bridge |
| **24V_ISO** (U3 pin 3) | **GND_ISO** (U3 pin 4) | NO continuity | ISO short → opto LED rail problem |
| **CN39 pin 1** (VFD_10V) | **GND** | NO continuity | Spindle output short |

**What to do if any test beeps:**
1. **DO NOT POWER ON**
2. Inspect the PCB under a loupe — look for solder bridges on power pins
3. If the bridge is on the QFN-80 (RP2350) → rework with flux + braid + hot air
4. If the bridge is under a TH component → desolder, clean, resolder

### 1b. TH component polarities (visual check)

Before power-on, visually verify **one more time**:

- ✅ **D7 Zener** — the cathode (black band on the body) faces the **SPIN_10V** net (the silkscreen marks the cathode)
- ✅ **C7 100µF electrolytic** — positive lead (longer) on the **+5V** side (silkscreen: + symbol)
  - The **negative lead** has a white band on the can (cylindrical body)
- ✅ **U3 B2424S** — pin 1 marker (dot or "1") aligned with the PCB silkscreen

**A C7 polarity mistake = explosion at power-on.** Check TWICE.

### 1c. Connector seating
- ✅ All KEFA connectors (CN22-CN42) sit firmly with no loose pins
- ✅ RJ1 RJ45 correctly oriented, LEDs facing outward
- ✅ MicroSD slot (CARD1) clicks via the push-push mechanism

---

## ⚡ Step 2: First power-on (with a current-limited supply)

> 💡 **Pro tip:** if you have a lab power supply with a **current limit** feature, set the limit to **500mA** on the first try. If the board draws more than that → something is shorted, and the PSU will fold back before anything is destroyed.

### 2a. Prepare the power supply
- **24V DC, 2A min** (Mean Well RS-50-24 or similar)
- **Polarity:** red wire = **+24V**, black = **GND** (or blue/brown on industrial ones)
- 🔴 **WARNING: the 24V input has NO reverse-polarity protection.** Swapping +24V and GND on CN42 **will damage the board**. Triple-check polarity with a multimeter before every power-on.
- Connect to **CN42**:
  - **Pin 1 = +24V**
  - **Pin 2 = GND**

### 2b. Power ON

1. Keep the board away from metal surfaces (ESD safety)
2. **Turn on the power supply** (flip the switch or plug in the cable)
3. **Watch the LEDs** in the next 2 seconds:

### 2c. LED indicator sequence (expected)

> **Naming note:** the BOM uses `LED1-LED6` (KT-0805G) for the power LEDs.
> `D1` is the **SS54 ORing Schottky on the +5V rail** (TPS5430 buck → L3 → D1 → +5V; it blocks the USB-C 5V from back-feeding the buck). It is **not** a 24V reverse-polarity diode, and not a LED.

| LED | Location | When it lights | What it indicates |
|---|---|---|---|
| **LED1 - 24V power** | Near CN42 | Immediately at power-on | +24V rail OK |
| **LED2 - 5V power** | Near TPS5430 | ~10ms later | +5V buck working |
| **LED3 - 3V3 power** | Near AMS1117 | ~50ms later | +3.3V LDO working, MCU powered |
| **LED4 - 24V_ISO** | Near U3 | ~100ms later | ISO rail active (opto supply) |
| **LED5 - USB activity** | Near USB-C | OFF (no USB cable) | Off is OK with no PC connection |
| **LED6 - VFD output** | Near U23 (LM358) | Off at idle | Brightens with spindle PWM (0-10V output) |

**If any of LED1-LED4 does not light up:**
- **Power off immediately** (cut power)
- See the Troubleshooting section below

### 2d. Sensory check (smell + touch)

In the first 30 seconds:
- ❌ **NO burning smell** or smoke from any component
- ❌ **NO "spuckling" sounds** (sign of a short that arcs)
- ✅ **Components are COLD** or at most mildly warm:
  - TPS5430 (U1) and AMS1117 (U2) can be **pleasantly warm** (~40°C) under normal load
  - RP2350B (U4) should be **cold** (idle ~32°C)
  - LM358 (U23) should be **cold**

**If any component becomes too hot to touch (>60°C) within 30 seconds:**
- **CUT POWER IMMEDIATELY**
- A short circuit or misplaced component is the likely cause

---

## 🔬 Step 3: Voltage verification (multimeter)

**Multimeter in DC Voltage mode (0-50V range).**

### 3a. Power rail measurements

With **power on**, measure the following (black probe on GND, red on the test point):

| Test point | Expected | Tolerance | Action if out of spec |
|---|---|---|---|
| **CN42 pin 1 (24V_IN)** | 24.00V | 23.5 - 24.5V | Check the power supply |
| **+5V rail (LM358 pin 8)** | 5.00V | 4.95 - 5.05V | TPS5430 buck problem |
| **+3.3V rail (RP2350 pin 50)** | 3.30V | 3.25 - 3.35V | AMS1117 LDO problem |
| **+24V_ISO (U3 pin 3)** | 24.00V | 23.0 - 25.0V | B2424S isolated DC/DC problem |
| **CN39 pin 1 (VFD_10V)** | 0.00V | 0 - 0.1V | LM358 output stuck — at 0% PWM it should be 0V |

### 3b. Ground reference verification (input-side isolation)

**v1 uses optical isolation ONLY on the inputs** (CN22-CN31). Stepper outputs, VFD, AUX (SSR), and communication share the MCU ground. The test verifies the input-side barrier:

| Test point 1 | Test point 2 | Expected | What it means |
|---|---|---|---|
| **GND (USB shell)** | **GND_ISO (CN23 pin 3, isolated input side)** | **NO continuity** in DC | Input-side barrier works ✓ |
| **CGND (RJ45 shell)** | **GND** | ~0V through 1MΩ + 1nF/2kV | Bob Smith termination works |
| **GND (USB shell)** | **GND (CN40 pin 5, AUX)** | **HAS continuity** (≈0Ω) | Output side shares MCU GND (by design) ✓ |

⚠️ **Do not look for GND on a stepper connector.** CN34-CN38 are `+5V · STEP · DIR · EN` —
common anode, no ground pin (CN34 pin 4 is `EN_X_5V`). Probing pin 4 against USB GND will
**not** read 0 Ω, and that is correct behaviour, not a fault. CN40 pin 5 is a real GND on the
same non-isolated side, so it is the point that answers this test.

**If GND and GND_ISO have continuity (the buzzer beeps):**
- The input-side isolation barrier is breached
- Probably a solder bridge across the 2mm void barrier
- See Troubleshooting

**Note:** in v1 the stepper, VFD, and AUX output sides share the MCU ground (only the input side is isolated).

---

## 💾 Step 4: USB enumeration test

### 4a. Connect the USB-C cable
- PC side of the USB-C cable into the computer
- RectaBot side into the USB-C port on the board

### 4b. Observe
- **LED5 (USB activity LED)** should light up
- Windows/macOS should recognize a **new USB device**:
  - **Without firmware:** "USB Device" with unknown VID/PID (normal)
  - **With BOOTSEL active:** "RPI-RP2" Mass Storage Device

### 4c. BOOTSEL test
1. Press and hold the **BOOT button** (marked B on the PCB)
2. Press and release the **RESET button** (marked R on the PCB)
3. Release the BOOT button
4. **Expected:** Windows plays a "USB connected" sound, the `RPI-RP2` drive opens

**If BOOTSEL doesn't work:**
- The BOOT button is poorly soldered — check connectivity
- The RESET button does not make a clean contact — check continuity with the multimeter

---

## 🌐 Step 5: Ethernet PHY test (optional)

### 5a. Visual check
1. Connect an **RJ45 patch cable** (Cat5e or Cat6) between RJ1 and your router
2. **LINK LED on RJ1** should light up (green)
3. **ACT LED on RJ1** should blink (yellow)

### 5b. Without firmware
Without firmware, the W5500 doesn't initialize, but the RJ45 magnetics work at the physical level — the LINK LED should light up if the hardware is OK.

### 5c. With firmware (later)
RectaBot firmware comes up on a **fixed address, not DHCP**: `192.168.5.1 / 255.255.255.0`,
hostname `rectabot`. Give the PC an address on the same subnet (e.g. `192.168.5.20/24`) and:
```
ping 192.168.5.1
```
A router is not needed — a direct cable between the PC and RJ1 works. If the board answers
nowhere, it is on DHCP: either the address was changed by hand (`$300..$304`) or the image
predates 2026-07-29, when the static default first actually took effect. Connect over USB and
read `$$` to find out which.

---

## 🆘 Troubleshooting

### Problem: LED1 (24V power) does not light up
**Causes:**
- Wrong power-supply polarity (CN42 pin 1 and 2 swapped) — 🔴 **the 24V input has NO reverse-polarity protection; reversing it can damage the board.** Disconnect and check the board before retrying.
- Trace broken between CN42 and the power tree
- LED1 or its series resistor damaged

**Solution:**
1. Multimeter on the CN42 pins — verify 24V with correct polarity (+24V on pin 1, GND on pin 2)
2. ⚠️ If you applied reverse polarity, there is no protection — inspect the board for damage before powering again
3. Inspect the CN42 solder joints

---

### Problem: 24V LED is lit, but 5V LED is not
**Causes:**
- TPS5430 buck converter (U1) has a problem
- Inductor L1 (22µH) cold joint or soldered incorrectly
- VSENSE divider (resistors) wrong → buck does not enter switching mode

**Solution:**
1. Multimeter on U1 pin 7 (VIN) — should be 24V ✅
2. Multimeter on U1 pin 8 (PH) — should show switching ~50% duty at ~500kHz
3. Multimeter on the L1 output — should be 5V DC
4. If L1 is cold and there is no voltage → reflow L1 with hot air

---

### Problem: 5V lights up, 3.3V does not
**Causes:**
- AMS1117 LDO (U2) cold joint
- Output capacitor (C19 or similar) is shorted to GND
- RP2350B power pins draw too much current (short on the chip)

**Solution:**
1. Multimeter on U2 pin 3 (VIN) — should be 5V
2. Multimeter on U2 pin 2 (VOUT) — should be 3.3V
3. If VIN=5V and VOUT=0V → AMS1117 is damaged or the output is shorted
4. Cut power and run a continuity test between 3.3V and GND — if it beeps, look for a short on the MCU side

---

### Problem: 24V_ISO LED does not light up
**Causes:**
- B2424S-2WR3 (U3) cold joint on its 4 pins
- VCC side (24V_IN) has no voltage on pin 1
- Output side shorted to GND_ISO

**Solution:**
1. Multimeter on U3 pin 1 (VIN+) — should be 24V
2. Multimeter on U3 pin 2 (VIN-) — should be GND
3. Multimeter on U3 pin 3 (VOUT+) — should be 24V (no load) or 23V (with LED load)
4. If pin 3 = 0V → U3 is defective or soldered incorrectly

---

### Problem: Component gets hot
**Most common causes:**
- **RP2350B hot** → short on a 3.3V VDD pin, or a pad bridge on the QFN-80
- **TPS5430 hot (>60°C)** → 5V rail is overloaded (5V → GND short)
- **AMS1117 hot** → 3.3V rail is overloaded
- **B2424S hot** → 24V_ISO short

**Solution:**
1. **Cut power IMMEDIATELY**
2. Wait 1-2 minutes to let it cool down
3. Multimeter continuity test for all power rails (see Step 1a)
4. Visually look for solder bridges on the overheating chip
5. If you find no short → the chip is probably damaged (replace)

---

### Problem: BOOT/RESET doesn't enter BOOTSEL
**Causes:**
- Pull-up resistors missing on BOOT/RESET pins
- Side-tactile buttons whose mechanism doesn't click reliably
- 100nF debounce cap missing

**Solution:**
1. Multimeter continuity on the BOOT button — press and release, listen for the click
2. Verify the 10kΩ pull-up on the BOOT pin
3. If BOOTSEL doesn't work → flash via the **SWD interface** (H1 header) using **picoprobe** or **J-Link**

---

## ✅ Power-On Checklist (sign off when done)

- [ ] Pre-power continuity tests passed — no short circuits
- [ ] D7 cathode orientation verified
- [ ] C7 polarity verified
- [ ] 24V power-on with no sparks, smoke, or hot components
- [ ] LED1-LED4 are all active
- [ ] +5V rail = 5.00 ± 0.05V
- [ ] +3.3V rail = 3.30 ± 0.05V
- [ ] +24V_ISO rail = 24.0 ± 1.0V
- [ ] Input-side isolation OK (GND ≠ GND_ISO, no continuity)
- [ ] USB enumeration OK (PC sees the device)
- [ ] BOOTSEL enters Mass Storage mode (`RPI-RP2`)

**If all 10 boxes are ✅** → the board is ready for firmware flash and configuration.

Next step: [Quick_Start_Guide.md](Quick_Start_Guide.md) Step 5 (Firmware Flash).

---

## 📝 First Power-On Log Template

Fill this in as you power on your board for the first time — a handy record of the checks below:

```
RectaBot v1.0 — First Power-On Log
==================================
Date: ___________
Board #: ____
Inspector: ___________

Pre-power tests:
  [ ] 24V-GND short test: PASS / FAIL
  [ ] 5V-GND short test: PASS / FAIL
  [ ] 3.3V-GND short test: PASS / FAIL
  [ ] D7 polarity: VERIFIED
  [ ] C7 polarity: VERIFIED

Power-On:
  LED1 (24V):  ON / OFF
  LED2 (5V):   ON / OFF
  LED3 (3V3):  ON / OFF
  LED4 (ISO):  ON / OFF
  LED5 (USB):  ON / OFF
  LED6 (VFD):  ON / OFF

Voltage measurements:
  +5V rail:    _____ V (spec: 4.95-5.05)
  +3.3V rail:  _____ V (spec: 3.25-3.35)
  +24V_ISO:    _____ V (spec: 23-25)

USB Enumeration:  PASS / FAIL
BOOTSEL test:     PASS / FAIL
Ethernet LINK:    PASS / FAIL / N/A

Notes / Issues:
________________________________
________________________________
```

---

*Stay careful. Don't rush. The multimeter is your best friend.* 🔬⚡

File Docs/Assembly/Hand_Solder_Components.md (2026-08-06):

# RectaBot v1.0 — Hand-Soldered Components Reference

**Components YOU solder by hand after receiving the board from JLCPCB.**

⚠️ **IMPORTANT:** JLCPCB **DOES NOT SHIP** these components — all TH parts must be ordered separately from LCSC.
Confirmed via JLCPCB chat (Desmond, 04.06.2026):
> "If you didn't select them to be assembled at the ordering page, we will not charge them and hence we will not send them to you."

See: [LCSC_Additional_Order.csv](../Manufacturing/LCSC_Additional_Order.csv) for the full list with LCSC codes.

---

## 📥 How the board arrives

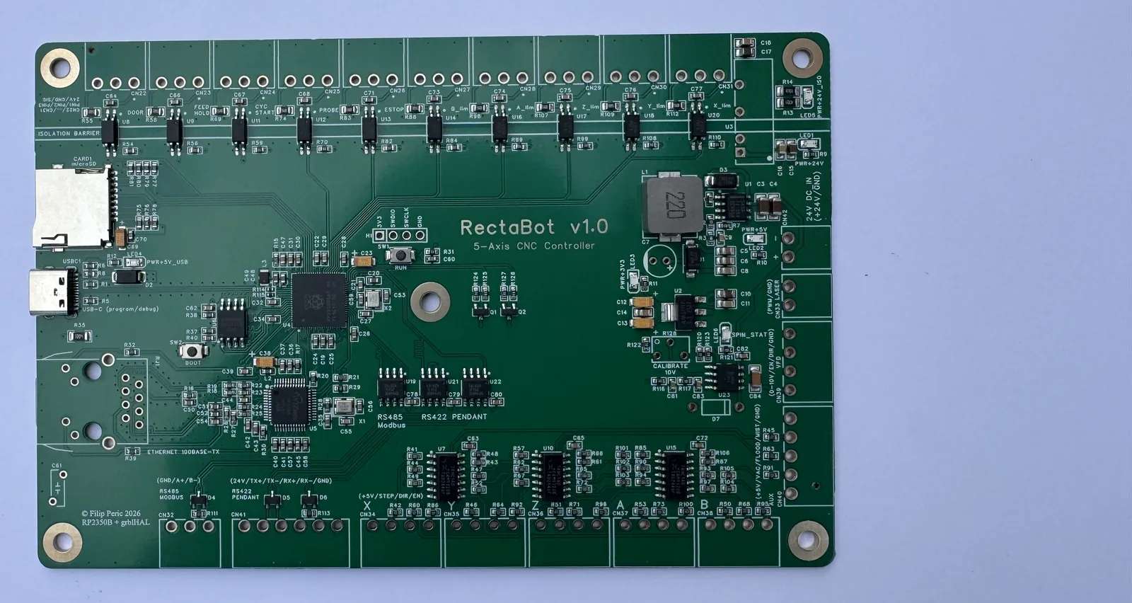
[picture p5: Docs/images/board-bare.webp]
RectaBot v1.0 — the board as it arrives from JLCPCB, SMT-assembled with no through-hole parts


This is exactly how the board ships from JLCPCB: **all SMT parts pre-assembled**, but **none of the through-hole components** — no screw terminals, no RJ45, no DC/DC module, no SWD header, and none of the electrolytic / trim-pot / Zener. You add the 28 TH parts listed below by hand.

---

## 📦 Component list (by designator)

| # | Designator | Value | Footprint | LCSC | Mounting |
|---|---|---|---|---|---|
| 1 | **C7** | 100µF electrolytic | TH BD6.0-P2.50 | C2873969 | Vertical, watch polarity (-/+ on silkscreen) |
| 2 | **C61** | 1nF / 2kV ceramic | TH L6.8-W2.6-P5.08 | C2976624 | Bob Smith chassis coupling |
| 3 | **CN22** | KF2EDGR-3.5-3P | TH 3-pin | C441172 | DOOR input |
| 4 | **CN23** | KF2EDGR-3.5-3P | TH 3-pin | C441172 | FEED HOLD input |
| 5 | **CN24** | KF2EDGR-3.5-3P | TH 3-pin | C441172 | CYCLE START input |
| 6 | **CN25** | KF2EDGR-3.5-3P | TH 3-pin | C441172 | PROBE input |
| 7 | **CN26** | KF2EDGR-3.5-3P | TH 3-pin | C441172 | ESTOP input |
| 8 | **CN27** | KF2EDGR-3.5-3P | TH 3-pin | C441172 | B_LIMIT input |
| 9 | **CN28** | KF2EDGR-3.5-3P | TH 3-pin | C441172 | A_LIMIT input |
| 10 | **CN29** | KF2EDGR-3.5-3P | TH 3-pin | C441172 | Z_LIMIT input |
| 11 | **CN30** | KF2EDGR-3.5-3P | TH 3-pin | C441172 | Y_LIMIT input |
| 12 | **CN31** | KF2EDGR-3.5-3P | TH 3-pin | C441172 | X_LIMIT input |
| 13 | **CN32** | KF2EDGR-3.5-3P | TH 3-pin | C441172 | RS485 Modbus (GND/A+/B−) |
| 14 | **CN33** | KF2EDGR-3.5-2P | TH 2-pin | C441171 | Laser PWM / GND |
| 15 | **CN42** | KF2EDGR-3.5-2P | TH 2-pin | C441171 | 24V DC INPUT |
| 16 | **CN34** | KF2EDGR-3.5-4P | TH 4-pin | C441173 | X Stepper (+5V/STEP/DIR/EN — common anode, no GND pin) |
| 17 | **CN35** | KF2EDGR-3.5-4P | TH 4-pin | C441173 | Y Stepper |
| 18 | **CN36** | KF2EDGR-3.5-4P | TH 4-pin | C441173 | Z Stepper |
| 19 | **CN37** | KF2EDGR-3.5-4P | TH 4-pin | C441173 | A Stepper |
| 20 | **CN38** | KF2EDGR-3.5-4P | TH 4-pin | C441173 | B Stepper (Y2 tandem) |
| 21 | **CN39** | KF2EDGR-3.5-4P | TH 4-pin | C441173 | Spindle VFD (10V/EN/DIR/GND) |
| 22 | **CN40** | KF2EDGR-3.5-5P | TH 5-pin | C441174 | AUX (5V/VAC/FLOOD/MIST/GND) |
| 23 | **CN41** | KF2EDGR-3.5-6P | TH 6-pin | C441175 | RS422 Pendant (24V/TX+/TX-/RX+/RX-/GND) |
| 24 | **D7** | 1N4742A Zener 12V | TH DO-41 | C140853 | Watch the cathode (band) — it faces the SPIN_10V net |
| 25 | **H1** | PZ254V-11-04P | TH 4-pin 2.54mm | C2691448 | SWD debug header |
| 26 | **R128** | PV37W103C01B00 trim pot 10k | TH PV37W | C6630214 | Spindle 0-10V gain calibration |
| 27 | **RJ1** | J1B1211CCD | TH RJ45 | C910371 | Ethernet with integrated magnetics |
| 28 | **U3** | B2424S-2WR3 | TH 4-pin DC/DC | C5369487 | Isolated 24V→24V_ISO for opto LEDs |

**Total: 28 components for hand-soldering (all come with the JLCPCB board)**

---

## 🛠️ Soldering order (recommended)

### Phase 1: Lowest-profile components first
1. **D7** Zener (bend the leads into a "P" shape for stress relief)
2. **R128** trim pot
3. **H1** SWD header

### Phase 2: Medium height
4. **C7** electrolytic (polarity! shorter lead = minus)
5. **C61** ceramic chassis cap

### Phase 3: Taller components
6. **U3** B2424S DC/DC module
7. **RJ1** RJ45 connector (careful with the shield pins)

### Phase 4: Connectors (tallest)
8. All **CN22-CN42** screw terminals (KEFA)

### Phase 5: Verification
- Visual inspection of solder joints
- Continuity test with the multimeter (GND to main pins)
- Power-on test without main components connected

---

## ⚠️ Specific notes

### **D7 1N4742A Zener — polarity CRITICAL**
- The cathode (band on the body) faces **SPIN_10V** (output signal)
- The anode (no band) goes to **GND**
- If reversed → the Zener never conducts → no VFD protection

### **C7 100µF electrolytic — polarity CRITICAL**
- The positive lead (longer) faces the **+5V** side
- The negative lead (shorter, white band on the can) faces **GND**
- If reversed → explosion on first power-on!

### **RJ1 RJ45 — watch the shield pins**
- It has 2 extra pins for chassis ground/shield
- They must be soldered for EMI performance
- Bob Smith termination works only if the shield is connected

### **R128 trim pot — calibration**
- After soldering: connect the VFD and tune so that at max PWM you get exactly 10.0V
- See [VFD_Wiring_Guide.md](../Reference/VFD_Wiring_Guide.md) for details

---

## 📋 What YOU must purchase separately (NOT in the JLCPCB package)

**ALL components on this list (28 TH parts) + male KEFA mating connectors.**

See: [LCSC_Additional_Order.csv](../Manufacturing/LCSC_Additional_Order.csv) — full BOM for 5 boards (~$50 with male connectors).

---

## ✅ The finished board

RectaBot v1.0 — after hand-soldering the through-hole parts: all screw terminals, RJ45, DC/DC module and headers in place

Once the 28 TH parts are soldered, the board is complete: every screw terminal, the RJ45 jack, the isolated DC/DC module and the SWD header in place — ready to wire up and flash.

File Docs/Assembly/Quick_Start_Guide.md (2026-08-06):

# RectaBot v1.0 — Quick Start Guide

**From an unboxed board to the first motor movement — step by step.**

Estimated time: **2-3 hours** (including soldering 28 TH components).

---

## 📦 What arrives

If you had the boards made from the files in [`Docs/Manufacturing/`](../Manufacturing/),
your parcels hold this. Two of them, because the two halves come from different places.

### From the PCB assembler
- ✅ **RectaBot v1.0 PCB** with the SMT components already mounted
- ✅ ENIG gold finish (durable, and pleasant to solder onto)
- ❌ **No through-hole components** — an assembler only fits what you selected when
  ordering, and the TH parts are not part of the SMT run. You solder those yourself
  (see [Hand_Solder_Components.md](Hand_Solder_Components.md))
- 📄 The invoice — keep it, customs may ask

### From the parts distributor
- ✅ **28 through-hole components** per board, plus whatever the minimum order
  quantities forced you to buy extra of
  - Detailed list: [Hand_Solder_Components.md](Hand_Solder_Components.md)
- ✅ **Male KEFA connectors** (KF2EDGK series) for the screw terminals
- 📄 The invoice — same reason

If you bought an assembled board instead, skip both lists and the soldering with them;
start at [First_Power_On_Procedure.md](First_Power_On_Procedure.md).

### What YOU need to provide (not in the package)

| Tool / Material | Details |
|---|---|
| **Soldering iron** | TS100 / Pinecil / Hakko FX-888D, set to 320-350°C |
| **Solder** | 60/40 Sn/Pb 0.6-0.8mm with rosin core |
| **Multimeter** | Any digital one with continuity and voltage modes |
| **Tweezers** | ESD-safe, for holding TH components during soldering |
| **Loupe / microscope** | Useful for visual QFN-80 RP2350B inspection before power-on |
| **24V DC power supply** | 24V / 2A min, e.g. Mean Well RS-50-24 or screw-terminal adapter |
| **USB-C cable** | Data + power, for firmware flash and debug |
| **Test pins / Dupont cables** | For probing rails |

---

## 🔍 Step 1: Visual inspection (10 min)

**Before you solder anything:**

### 1a. Top side check
Place the PCB under a loupe/microscope and verify:

- ✅ All QFN-80 (RP2350B) pads have a clean ENIG finish (no oxidation)
- ✅ The W5500 QFN and SP3485 SOIC-8 packages are correctly oriented (pin 1 marker = bottom-left)
- ✅ No **solder bridges** between adjacent RP2350B pins (the biggest risk)
- ✅ LM358 (U23), 2N7002 (Q1/Q2) are in place
- ✅ All LEDs (LED1-LED6, marked KT-0805G in BOM) are present and correctly oriented
- ✅ The TF (microSD) connector is well soldered and clicks via its push-push mechanism

### 1b. Bottom side check
- ✅ R36 and C33 are DNP (Do Not Populate) and are NOT present on the bottom — that's expected
- ✅ No visible PCB damage (scratches, exposed traces)

### 1c. What to do if you find a problem
- **Solder bridge** → rework with flux + braid
- **Cold joint** (matte, lumpy surface) → resolder with fresh flux
- **Misaligned IC** → reflow with hot air (300°C, 30s)
- **PCB damage / tear** → contact JLCPCB support with photos

---

## 🔧 Step 2: Hand-soldering TH components (60-90 min)

**Follow the order from [Hand_Solder_Components.md](Hand_Solder_Components.md):**

### Phase A: Lowest-profile components first
1. **D7** Zener 1N4742A — `cathode (band) must face the SPIN_10V net`
2. **R128** PV37W trim pot — orientation doesn't matter
3. **H1** SWD header — straight, 4-pin

### Phase B: Medium-height components
4. **C7** 100µF electrolytic — **POLARITY CRITICAL** — positive lead (longer) to +5V
5. **C61** 1nF/2kV ceramic chassis cap — Bob Smith capacitor

### Phase C: Taller components
6. **U3** B2424S-2WR3 — isolated DC/DC, 4-pin SIP
7. **RJ1** RJ45 J1B1211CCD — watch the shield pins (chassis ground)

### Phase D: Connectors (tallest, last)
8. **CN22-CN42** screw terminals (KEFA KF2EDGR)
   - Pin 1 of each connector aligns with the **PCB silkscreen marker** (a thicker line or square)
   - Short but strong solder joints — TH connectors take mechanical stress

### ⚠️ Polarities you MUST remember
| Component | Polarity info |
|---|---|
| **D7 1N4742A** | The cathode (black band) goes to **SPIN_10V**. Reversed = no overvoltage protection. |
| **C7 100µF** | Positive lead (longer) to the **+5V** side. Reversed = **explosion on first power-on!** |
| **U3 B2424S** | Pin 1 has a silkscreen dot — orient it to match the PCB silkscreen |
| **RJ1 RJ45** | Correctly oriented = LEDs face the PCB edge (outward) |

---

## 🧪 Step 3: Pre-power-on check (15 min)

**MANDATORY — do this BEFORE you connect 24V power!**

See [First_Power_On_Procedure.md](First_Power_On_Procedure.md) for the detailed procedure.

**Summary:**
1. Multimeter on continuity mode
2. Verify there are NO shorts:
   - 24V → GND (probe CN42 pin 1 and 2)
   - +5V → GND
   - +3.3V → GND
   - 24V_ISO → GND_ISO
3. Visually re-check the electrolytic polarity (C7) one more time

---

## ⚡ Step 4: First power-on (10 min)

**Detailed procedure with expected measurements:** [First_Power_On_Procedure.md](First_Power_On_Procedure.md)

**Summary:**

1. **Connect 24V** to CN42 (pin 1 = +24V, pin 2 = GND)
2. **Watch the LEDs:**
   - 24V power LED → lit ✅
   - 5V power LED → lit ✅
   - 3V3 power LED → lit ✅
   - 24V_ISO power LED → lit ✅
3. **Measure with the multimeter:**
   - +5V rail = 4.95 - 5.05V ✅
   - +3.3V rail = 3.25 - 3.35V ✅
   - +24V_ISO rail = 23.5 - 24.5V ✅
4. **NO SMOKE**, no crackling sounds, no overheating components

**If anything is off** → power down immediately and check the troubleshooting section in First_Power_On_Procedure.md.

---

## 💾 Step 5: Firmware flash (15 min)

### 5a. Enter BOOTSEL mode
1. Press and hold the **BOOT button** on the PCB
2. While holding BOOT, press and release the **RESET button**
3. Release the BOOT button
4. The RP2350B will enumerate as a **USB Mass Storage** device (drive `RPI-RP2`)

### 5b. Flash grblHAL firmware
1. Connect a USB-C cable PC ↔ RectaBot
2. Pick the `.uf2` that matches your machine's kinematics — use the [firmware configurator](https://rectabot.org/configurator/) or grab it from the firmware repo's `variants/` folder (e.g. `grblHAL_RectaBot_3axis_v1.0.uf2`, `..._4axis-a-ganged-y_v1.0.uf2`). RectaControl's Firmware panel can also flash it for you.
3. Open `RPI-RP2` in Explorer and drag-and-drop the `.uf2` into the drive
4. The drive disappears and the RP2350B reboots into grblHAL

### 5c. Verify the firmware
1. Open a serial monitor (PuTTY / Arduino IDE Serial Monitor / minicom)
2. Connect to the COM port (115200 baud, 8N1)
3. Send `$I` — you should see something like (a 4-axis build):
   ```
   [VER:1.1f.20260331:]
   [OPT:VNMPZTSL+2,100,1024,4,0]
   [AXS:4:XYZA]
   [BOARD:RectaBot v1.0]
   [DRIVER:RP2350@150MHz]
   ```
   `[AXS:4:XYZA]` confirms the axis count; the trailing `2` in `[OPT:...+2,...]` means a ganged/auto-square motor is active.

---

## ⚙️ Step 6: grblHAL configuration (20 min)

**Critical parameters for RectaBot v1.0:**

```
$0=5         ; Step pulse, microseconds
$1=25        ; Step idle delay, milliseconds
$2=0         ; Step invert OFF — Common Anode drivers need NO step invert (do NOT set 31)
$4=15        ; Enable invert — the 74HC14D inverts EN, so invert every axis: 7=3-axis, 15=4-axis, 31=5-axis
$5=0         ; Limit invert OFF — the opto inputs already read active-low
$6=1         ; Probe invert ON
; --- direction is PER MACHINE (depends on your wiring/mechanics), not a fixed value ---
$3=0         ; Direction invert — jog each axis; if it runs backwards, flip THAT axis's bit
$10=1        ; Status report options, mask
$11=0.010    ; Junction deviation, millimeters
$12=0.002    ; Arc tolerance, millimeters
$13=0        ; Report in inches, boolean
$20=0        ; Soft limits enable, boolean
$21=1        ; Hard limits enable, boolean
$22=1        ; Homing cycle enable, boolean
$23=3        ; Homing direction invert, mask
$24=25.000   ; Homing locate feed rate, mm/min
$25=500.000  ; Homing search seek rate, mm/min
$26=250      ; Homing switch debounce delay, milliseconds
$27=1.000    ; Homing switch pull-off distance, millimeters
$30=24000    ; Maximum spindle speed, RPM (for a 24kRPM VFD)
$31=0        ; Minimum spindle speed, RPM
$32=0        ; Laser-mode enable, boolean (leave 0 for spindle)
```

**Per-axis configuration** (X axis shown, same for Y/Z/A/B):
```
$100=80.000  ; X-axis steps per millimeter (depends on the driver)
$110=2000.000 ; X-axis maximum rate, mm/min
$120=200.000  ; X-axis acceleration, mm/sec²
$130=300.000  ; X-axis maximum travel, millimeters
```

---

## 🎮 Step 7: First axis test (10 min)

### 7a. Connect a DM556 driver to CN34 (X axis)

CN34 is a 4-pin **common-anode** stepper output. Silkscreen order is **+5V / STEP / DIR / EN** — there is **no GND pin**: the STEP/DIR/EN lines are actively pulled to GND by the on-board 74HC14D, and that is the return path.

- Pin 1 = **+5V** → DM556 **PUL+, DIR+, ENA+** (common all three `+` inputs to +5V)
- Pin 2 = **STEP** → DM556 **PUL−**
- Pin 3 = **DIR** → DM556 **DIR−**
- Pin 4 = **EN** → DM556 **ENA−**  *(optional — leave unconnected to keep the driver always enabled)*

**Common anode:** +5V feeds every `+` input on the driver, and the controller sinks each signal to GND to pulse it. Keep `$2=0` (step-invert off) — the 74HC14D idles HIGH and each step briefly pulls the opto low, which is correct for common anode. Setting `$2`≠0 holds the opto on at idle and can cause missed steps.

### 7b. Connect a motor to the DM556 outputs
- A+, A-, B+, B- (4-wire NEMA17/23 motor)
- Set the DM556 microstep DIP switches (e.g. 1600 steps/rev for 8 microsteps)

### 7c. Try a jog command in the serial monitor
```
$J=G91 X10 F500    ; Move 10mm to the right @ 500mm/min
$J=G91 X-10 F500   ; Move 10mm to the left
```

**What to expect:**
- ✅ The motor turns smoothly, without "skipping"
- ✅ Direction follows the DIR command
- ✅ It stops at the position
- ❌ If it jitters or doesn't move → see troubleshooting

---

## 🎯 Next steps

Once the X axis runs reliably:
1. **Repeat for Y, Z, A, B** (CN35-CN38)
2. **Connect limit switches** (CN27-CN31)
3. **Configure homing** (`$H` command)
4. **Connect the VFD** — see [VFD_Wiring_Guide.md](../Reference/VFD_Wiring_Guide.md)
5. **Connect coolant / vacuum relays to CN40** — read below before you buy or wire them
6. **Test G-code execution** with a sender (UGS, CNCjs, IO Sender)

### ⚠️ Wiring a relay to CN40 — which way round matters

`CN40` is `+5V · VAC · FLOOD · MIST · GND`. Wire each SSR control input between
**`+5V` (pin 1)** and its signal pin — the same common-anode arrangement as the stepper
drivers, which is why the `+5V` pin is on the connector at all.

| SSR control terminal | CN40 pin |
| :--- | :--- |
| `+` | **1** — `+5V` |
| `−` | **2** `VAC` (`M62`/`M63`) · **3** `FLOOD` (`M8`) · **4** `MIST` (`M7`) |

The signal passes through the 74HC14D inverter, so a coolant pin **idles at ~5 V and is
pulled to 0 V when the M-code turns the output on**. Wire the SSR to `GND` instead and
you get the exact opposite: the pump or vacuum runs **whenever the machine is idle**, and
switches **off** when the program calls for it. Nothing reports an error — it simply runs
until someone notices.

### Which relay to buy

Each pin is a 74HC14D channel behind a 330 Ω resistor — 25 mA absolute maximum, with `VOL`
guaranteed up to 4 mA. Both of these work:

**An optocoupler-input relay module** — the easy answer. Wire `VCC`→pin 1, `GND`→pin 5,
`IN`→the signal pin. It has a gain stage: a few mA from this pin lights an LED, whose
transistor pulls the 70–80 mA of coil current from the module's own `VCC`, so the board
never supplies the relay itself. Look for an input current of about 5 mA at 5 V.

**A solid-state relay wired straight on** — a **Fotek SSR-40 DA** was built and run this
way on the reference board:

| Fotek terminal | to |
| :--- | :--- |
| **1** | 230 V live in |
| **2** | 230 V out → load → neutral |
| **3** (control `+`) | `CN40` pin 1 — `+5V` |
| **4** (control `−`) | `CN40` pin 4 — `MIST` |

It switches from `M7`/`M9`, from the sender's coolant button, and survives repeated rapid
on/off. Measured: 5.07 V open circuit, **3.11 V across the control input**, ~5.9 mA, with
the output still pulling to ground. The Fotek's datasheet minimum is 3 V, so it clears.

What decides it is not the chip's current capability but how much voltage the 330 Ω leaves
for the relay. If a particular SSR needs more than roughly 3 V and will not trigger, put a
small P-channel MOSFET between — see [Pinout.md](../Reference/Pinout.md).

**All three outputs can drive one each, at the same time.** `MIST`, `FLOOD` and `VAC` come
off three *different* 74HC14D chips (`U7`, `U10`, `U15`), so a second and third SSR do not
pile onto the chip driving the first. Together they draw about **17.7 mA** from `CN40`
pin 1. Buy one relay per output and wire each control `−` to its own signal pin.

That margin belongs to the individual relay, though, not to how many of them you run — and
counterfeit Foteks are common. **Confirm each new one actually switches before you build it
into the machine.**

#### Industrial modules

DIN-rail interface relays (Phoenix Contact PLC-INTERFACE, Weidmüller TERMSERIES, Wago 859,
Omron G3RV-SR) are built to be driven by a PLC output that sources half an amp, so most of
them ask for 10–15 mA even on their 5 V models. Some low-current variants exist — check
that one number before ordering.

Their input stage is the same optocoupler the cheap module uses. What the money buys is the
output: contacts that survive, terminals that hold, and a housing that belongs on a
machine. For a mill that runs every day that is worth paying for; the electrical
requirement is identical either way.

A relay module's coils draw 70–80 mA each and kick when they release. If your module has a
**`JD-VCC` jumper**, pull it and feed `JD-VCC` from a separate 5 V supply — keeping grounds
common — so that kick stays off the same 5 V rail that carries your step pulses.

---

## 🆘 Troubleshooting

### Power rails out of spec
- **+5V < 4.9V** → TPS5430 buck may have a cold joint on L1 or the VSENSE divider
- **+3.3V < 3.2V** → AMS1117 LDO overloaded or poorly soldered
- **+24V_ISO < 23V** → B2424S DC/DC not working or 24V_IN too low

### LEDs don't light up
- **All LEDs off** → 24V isn't reaching the board (check CN42 polarity!)
- **Only the 24V LED is lit** → TPS5430 problem
- **24V + 5V LEDs lit, 3V3 off** → AMS1117 problem

### USB enumeration doesn't work
- **Drive does not appear** → wrong BOOT/RESET sequence, repeat it
- **Drive appears, then immediately disappears** → firmware file corrupted or wrong UF2

### Motor doesn't move
- **No motion / missed steps** → check `$2=0` (step invert must be OFF for the Common Anode drivers; `$2=31` holds the opto on at idle) and `$4` enable-invert matches your axis count (7/15/31)
- **Constant level on STEP** → 74HC14D not soldered properly
- **Motor "skips"** → microstep DIP switches don't match the $100 parameter
- **Axis runs the wrong way** → flip that axis's bit in `$3` (direction is per-machine)

---

## 📚 Further reading

- [Pinout.md](../Reference/Pinout.md) — complete GPIO map
- [Hardware_Design_Guidelines.md](../Reference/Hardware_Design_Guidelines.md) — electrical and mechanical design
- [VFD_Wiring_Guide.md](../Reference/VFD_Wiring_Guide.md) — how to wire various VFDs (analog 0-10V)
- [VFD_Modbus_Setup.md](../Reference/VFD_Modbus_Setup.md) — spindle control over RS-485/Modbus
- [Product_Specification_v1.0.md](../Reference/Product_Specification_v1.0.md) — complete datasheet

---

*Need help? Open an issue on GitHub or email hello@rectabot.org*

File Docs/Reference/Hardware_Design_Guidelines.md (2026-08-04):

# RectaBot Hardware Design Guidelines (KiCad / EasyEDA)

This document is a reference for laying out the PCB based on the approved architecture.

## 1. Layer stackup (4-layer PCB)
Given the choice of 4 layers and the need to minimize EMI (especially because of the VFD), the recommended *Layer Stackup* is:
- **Top Layer (Signal / Power routing):** signals for components on the top side, routing of short logic lines, and power.
- **Layer 2 (GND plane):** solid (uninterrupted) ground plane. Crucial for short return paths and for isolation under the W5500 SPI lines, as well as for cooling the TPS5430DDAR.
- **Layer 3 (Power plane / Signal):** islands (polygons) for +5V and +3.3V supplies. Optionally routing of control lines.
- **Bottom Layer (Signal):** routing of longer signal lines, e.g. from the microcontroller to connectors.

## 2. Power (Power Tree)
- **TPS5430DDAR (C9864) Buck Converter (24V → 5V):** design according to Texas Instruments recommendations. The *Exposed Pad* under the chip **must** be stitched with vias (thermal vias) into Layer 2 and the Bottom layer to efficiently dissipate heat and avoid overheating. The inductor should be shielded and placed as close to the chip as possible.
- **3.3V LDO (e.g. AMS1117-3.3 — C6186):** drops the voltage from 5V to 3.3V. Given the small voltage drop (1.7V difference), thermal design is extremely safe.

## 3. Communication (Isolation and EMI)
- **RS485 Modbus:** RectaBot v1.0 uses the **SP3485EN-L/TR** transceiver (works directly at 3.3V — no level shift needed as with MAX485). TVS protection via **PSM712-LF-T7** diodes on the A/B outputs — placed at the connector, not at the IC. For additional protection against VFD noise, digital isolators (e.g. SI8621) can be used with a separate isolated DC/DC supply (B0505S series) if a noise problem appears.
- **RS422 (Pendant):** SP3485EN-L/TR is used (two chips — one TX, one RX) for the Full Duplex link. Pay attention to matching and the termination resistor (120Ω) especially on the input side (RX) of a long cable.
- **W5500 (Ethernet):** route the SPI lines (RX, CS, SCK, TX) close together and always over a solid GND plane without interruption to preserve signal integrity. Place the RJ45 port as far as possible from high-voltage outputs/VFD connectors.

## 4. Axes (5V Common Anode to DM556)
- The grblHAL RP2350 chip outputs I/O signals at 3.3V. RectaBot v1.0 uses the **74HC14D** (Schmitt-trigger HEX **inverter**) for the 3.3V→5V level shift. Power the buffers from +5V from the main buck converter.
- Control outputs (Step, Dir, Enable) run in *Common Anode* mode: the DM556 optocoupler's `+` lead is permanently tied to +5V, and the 74HC14D pulls the `−` lead to GND to turn the opto on.
- The 74HC14D inverts, but the Common Anode opto conducts on a LOW cathode, so a grbl active-high step pulse lands correctly at the opto with **no** firmware step invert: **`$2=0`** (validated on the reference board — `$2`≠0 holds the opto on at idle and causes missed steps). The **ENABLE** line does need inverting because of the driver's ENA polarity: **`$4`** = all axes (7 for 3-axis, 15 for 4-axis, 31 for 5-axis). Limit/probe opto inputs use **`$5=0`** / **`$6=1`**. Direction (`$3`) is per-machine — set it from how each axis actually moves.
- *Heads up:* **the STEP pins must be consecutive.** grblHAL drives them from PIO
  (`STEP_PORT = GPIO_PIO`, `STEP_PINS_BASE = 8`), and a PIO state machine writes one
  contiguous field of bits across a pin range — so `GP8`-`GP12` is a hard requirement, not
  a preference. **Dir (`GP13`-`GP17`) and Enable (`GP18`-`GP22`) are ordinary GPIO**
  (`DIRECTION_PORT = GPIO_OUTPUT`, `GPIO_MAP`), individually mapped: they are numbered in
  runs for tidiness, and may be moved when drawing a new board. Direction only has to
  settle before the pulse (`$29` setup time), which needs no PIO.
- On the RP2350B a PIO instance sees a **32-GPIO window** — `0`-`31` by default, or
  `16`-`47` via `pio_set_gpio_base()`. Keep the step pins inside one window; `GP8`-`GP12`
  sits well within the default one, so no base shifting and no splitting across PIO
  instances.

### Alternatives considered for v2 (NOT in v1):
- **74HCT245** (octal bus transceiver) — does not invert, but uses more pins and does not clean up noise like a Schmitt trigger.
- **74LVC07A** (open-drain buffer) — works with external pull-up resistors to 5V, adds 6 resistors, but does not invert.
- v1 kept the **74HC14D** because it is Basic on JLCPCB (free assembly) and provides a clean Schmitt input.

## 5. Spindle Interface (0-10V + EN/DIR)

RectaBot v1 implements a **universal VFD interface** on connector CN39 (4-pin KF2EDGR-3.5):
- Pin 1: `VFD_10V` — analog speed reference 0-10V DC
- Pin 2: `VFD_EN` — Run/Enable, active LOW open-drain
- Pin 3: `VFD_DIR` — Direction, active LOW open-drain
- Pin 4: `GND` — signal ground

### 5.1 PWM → 0-10V Converter (LM358DR2G)

**Topology:** non-inverting op-amp with a two-stage RC filter + Zener clamp + LED indicator.

**Components and layout:**
- **U23 = LM358DR2G** (Basic, SOIC-8) — dual op-amp, VCC = 24V_IN; rail-to-rail is not an issue on a 24V supply.
- **Filter stage 1:** R116 (10k) + C81 (100nF) — cutoff 159Hz, attenuates the PWM carrier.
- **Filter stage 2:** R117 (10k) + C83 (100nF) — second-order filtering, total 88dB at 25kHz PWM.
- **Gain network:** R122 (10k) + R128 (10k trim pot PV37W) + R120 (10k) → safe gain range **1.5-3.0** (max 9.9V from 3.3V PWM).
- **Overvoltage clamp:** R123 (1kΩ) in series + **D7 = 1N4742A 12V Zener (TH, hand-soldered)** + C84 (10nF) — clamps to 12V max even if the op-amp fails.
- **LED indicator:** the U23B section configured as a unity buffer for VFD_10V → R121 (2k) → LED6 (visual indicator of the real speed).

**Calibration:** tune trim pot R128 with the multimeter so that at 100% PWM (M3 S24000) you get exactly **10.0V** on CN39 pin 1.

### 5.2 EN/DIR open-drain buffers (2× 2N7002)

**Topology:** N-MOSFET open-drain, gate pull-down failsafe.

**Components:**
- **Q1, Q2 = 2N7002** (Basic, SOT-23) — N-MOSFET, 60V Vds rating, sufficient for any industrial VFD with up to 24V internal pull-up.
- **R125, R126 (1kΩ)** — gate series resistor, limits current during transients.
- **R124, R127 (10kΩ)** — gate pull-down, keeps the MOSFET OFF during MCU reset/boot (failsafe).

**Operational logic:**
| MCU pin (GP30/GP31) | MOSFET state | CN39 pin voltage | VFD sees |
|---|---|---|---|
| HIGH (3.3V) | ON (closed) | Pulled to GND (~0V) | **ACTIVE** (sinking input triggered) |
| LOW (0V) | OFF (open) | Floating / high-Z | INACTIVE (VFD pull-up holds HIGH) |
| MCU reset/boot | OFF (pull-down failsafe) | Floating | INACTIVE ✓ failsafe |

**Why this is safe:**
- The 2N7002 Drain blocks up to **60V** → if the VFD has a 24V internal pull-up, **voltage does NOT come back into the RP2350B pin**.
- The pull-down R124/R127 guarantees the spindle **never starts by itself** during MCU reset, BOOT, firmware update, or crash.
- Open-drain topology means you can connect multiple VFDs in parallel (e.g. dual spindle), each with its own pull-up.

### 5.3 PCB layout notes for the Spindle section

- **PWM signal routing** (GP27 → R116): short trace, do NOT route across the isolation void. Spindle PWM stays in the GND_MCU domain.
- **U23 LM358 decoupling:** 100nF (C82) very close to pin 8 (VCC). Without it, oscillations occur at high LED current.
- **D7 Zener placement:** hand-soldered TH (DO-41) → place **exactly between R123 and CN39 pin 1**, with the cathode (band) facing the CN39 side.
- **R128 trim pot:** place it so the adjust screw is accessible **without disassembling the board** — top-adjust orientation.
- **Ground reference:** CN39 pin 4 (GND) must be a **dedicated ground trace** to U23 GND, not shared with the noisy step/dir ground.
- **TVS on VFD_EN/VFD_DIR:** optional in v1 (2N7002 60V Vds is sufficient), TVS array planned in v2 for better EMC compliance.

### 5.4 VFD compatibility (summary)

| VFD Family | Digital Input Type | Works out-of-the-box? |
|---|---|---|
| Huanyang HY01/HY02 | Sinking (NPN) | ✅ Yes |
| Lapond SVD-EM | Sinking (NPN) | ✅ Yes |
| Delta VFD-M/EL | Sinking (NPN) | ✅ Yes |
| Hitachi WJ200 | Sinking (NPN) | ✅ Yes |
| ATO inverter | Sinking (NPN) | ✅ Yes |
| Siemens G120 | Sourcing (PNP) | ⚠️ Needs external relay module |
| ABB ACS580 | Sourcing (PNP) | ⚠️ Needs external relay module |
| Schneider ATV | Sourcing (PNP) | ⚠️ Needs external relay module |

**Detailed instructions by VFD model:** [VFD_Wiring_Guide.md](VFD_Wiring_Guide.md).

### v2 planned improvement
- Add an optional **2× Omron G6K-2P-Y relay** for out-of-the-box PNP/sourcing VFD compatibility (integrated relay tier).

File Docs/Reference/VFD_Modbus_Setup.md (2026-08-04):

# RectaBot — VFD Spindle Control over Modbus (RS-485)

**Version:** 1.0 | **Hardware:** RectaBot v1.0 | **Firmware:** grblHAL

This guide covers **digital** spindle control: the controller talks to the VFD over
RS-485 / Modbus RTU, so speed, run/stop and direction travel as messages instead of
as an analog voltage and two dry contacts.

> For **analog** control (0-10 V on CN39 + enable/direction lines) see
> [VFD_Wiring_Guide.md](VFD_Wiring_Guide.md). Both methods work; this one is the
> better of the two where the VFD supports it — see below.

---

## Why Modbus instead of 0-10 V

| | 0-10 V analog | Modbus RS-485 |
|---|---|---|
| Speed accuracy | analog chain (PWM → filter → op-amp), a few % error | exact — a number, not a voltage |
| Feedback | none; the sender displays what it *asked for* | real spindle RPM, current, fault state |
| Wiring | 3 signal wires + GND | 2 wires (A/B) + GND |
| Noise immunity | analog line next to stepper cables | differential pair, far more robust |
| Diagnostics | none | VFD faults surface as `ALARM:19` |

The trade-off is setup: the VFD must be told to take its commands from the bus, and
its parameters must describe the motor honestly, because **grblHAL reads the RPM
range out of the VFD** (see the register table below).

> ### The reason that last row matters
> An analog spindle is commanded blind: the controller puts out a voltage and never
> learns whether anything acted on it. If the drive faults mid-cut — lost phase,
> overheat, overcurrent, a pulled wire — the spindle coasts to a stop while the
> machine keeps driving the cutter through the material.
>
> Over Modbus the controller is in a conversation, so a drive that stops answering
> raises `ALARM:19` and the program stops with it. Worth verifying once on your own
> machine: with the spindle idle, pull the VFD's mains and confirm the alarm appears.

---

## 1. Wiring

RS-485 lives on **UART1** and needs a transceiver (MAX485 or a ready-made module):

| Signal | RP2350 pin | To transceiver |
|---|---|---|
| RS485 TX | `GP24` | DI |
| RS485 RX | `GP25` | RO |
| RS485 DE/RE | `GP26` | DE + RE (tied) |

From the transceiver to the VFD:

```
A  ────────────► A+  (or 485+ / RS+ / D+)
B  ────────────► B−  (or 485- / RS- / D-)
GND ───────────► GND (or COM / ACM)   ← do NOT skip this
```

Three rules that account for most "it does not talk" cases:

1. **A/B are a pair, not interchangeable with a swap of convenience.** If nothing
   answers, swapping A and B is the first thing to try — it costs nothing.
2. **Share the ground.** A differential pair still needs a common reference. A
   missing GND gives intermittent, weather-dependent behaviour, which is worse
   than a clean failure.
3. **One twisted pair, away from motor cables.** If the run is long (> 10 m) or the
   bus has several devices, terminate the far end with 120 Ω.

---

## 2. Pick the driver in the firmware

The shipped firmware has all VFD protocols compiled in; you select one at runtime:

| Setting | Meaning |
|---|---|
| `$395` | Spindle type — pick the driver that matches your VFD |
| `$476` | Modbus address of the VFD bound to spindle 1 (must match the address set in the VFD), default `1` |
| `$461` | RPM ↔ Hz factor (only used by drivers that need it) |

> ### ⚠️ Why `$476` and not `$460`
> Most grblHAL documentation names `$460` for the VFD's Modbus address, and on builds
> carrying a single spindle that is correct. The shipped RectaBot firmware compiles in
> every VFD protocol (`N_SPINDLE=8`), which puts grblHAL into its multi-spindle branch:
> `$460` stays registered but **hidden**, and the address you edit is **`$476`** —
> "Spindle 1 ModBus address" (`spindle/vfd/spindle.c`). Both write the same value, so
> `$460=…` still takes; it simply never shows up in `$ES` or in RectaControl's settings
> list, which reads like a broken firmware when it is not.
>
> If you ever run more than one VFD: `$477`, `$478`, `$479` address spindles 2, 3 and 4.
>
> `$476` **only appears once `$395` names a VFD driver and the board has been reset** —
> the setting is gated on the bound spindle actually being a VFD. Its absence before
> that point is expected, not a fault.

`$395` takes effect **after a board reset**. Two drivers cover the Huanyang family:

- **`Huanyang v1`** — the original HY protocol (HY01/HY02/HY03 series, `PD` parameters)
- **`Huanyang P2A`** — the newer P2A generation

Ask the board itself rather than trusting a table — **`$SPINDLESH`** enumerates what
this firmware actually carries, with the id `$395` expects. On the shipped build:

| `$395` | Driver |
|---|---|
| `0` | PWM (analog 0-10 V, the default) |
| `1` | Huanyang v1 |
| `2` | Huanyang P2A |
| `3` | Durapulse GS20 |
| `4` | Yalang YS620 (the drive is sold as YL620-A; the firmware spells it YS620) |
| `5` | MODVFD (generic Modbus) |
| `6` | H-100 |
| `7` | Nowforever |

In RectaControl: **Settings → Spindle & laser → Spindle type**, then reset the board.
`$I` lists every registered spindle, so you can confirm the driver came up.

---

## 3. The four registers grblHAL reads from the VFD

This is the part that surprises people. With the Huanyang v1 driver, the controller
**does not** take the speed range from its own settings — it interrogates the VFD at
startup (`spindle/vfd/huanyang.c`):

| Register | Read as | Used for |
|---|---|---|
| **PD144** | rated RPM at 50 Hz | converting every RPM command into Hz |
| **PD005** | max output frequency | the machine's maximum RPM |
| **PD011** | frequency lower limit | the machine's minimum RPM |
| **PD142** | rated motor current | spindle load calculation |

The conversion is `Hz × 10 = RPM × 5000 / PD144`.

> ### ⚠️ The PD144 trap
> If PD144 is left at its factory value (often `1440`, from a 4-pole industrial
> motor), **every commanded speed is wrong**. On a 24 000 RPM spindle, asking for
> 24 000 computes 833 Hz, PD005 clips that to 400 Hz, and the spindle simply runs
> flat out no matter what you command. If that happens, the sender is not at fault
> — PD144 is. (If the read fails entirely the driver falls back to 3000.)

---

## 4. Parameter set — worked example

Machine used for this example: **Huanyang HY03D023B** VFD (3.0 kW, 230 V input)
driving a **2.2 kW / 8 A / 24 000 RPM / 400 Hz** spindle.

### Motor block — from the spindle's nameplate, not the VFD's rating

| Register | Value | Why |
|---|---|---|
| `PD141` | `220` | rated motor voltage |
| `PD142` | `8.0` | rated motor **current** |
| `PD143` | `2` | poles — 24 000 RPM ÷ 400 Hz × 60 → 2-pole |
| `PD144` | `3000` | RPM at 50 Hz = 24 000 ÷ 400 × 50 |

> **Oversized VFD?** Fine, and often sensible — a 3.0 kW drive on a 2.2 kW spindle
> runs cooler and has headroom. But `PD142` must be the **motor's** 8 A, never the
> drive's rating: that number is what protects the spindle from overload, and what
> the load display is scaled against.

### Frequency and voltage block

| Register | Value | Why |
|---|---|---|
| `PD004` | `400` | base frequency |
| `PD005` | `400` | max output frequency → 24 000 RPM |
| `PD011` | `100` | lower limit → 6 000 RPM (see note) |
| `PD008` | `220` | max output voltage |
| `PD014` | `10`–`15` | acceleration time, seconds |
| `PD015` | `10`–`15` | deceleration time, seconds |

> **Why a 6 000 RPM floor:** on an **air-cooled** spindle the fan sits on the shaft,
> so running at a few hundred RPM to "take it easy" leaves it with almost no cooling
> — the opposite of gentle. A **water-cooled** spindle (the `GDZ` families) is cooled
> by the pump regardless of speed, so the floor there is not about heat but about
> torque: a V/f drive with no vector control gets weak and stall-prone down low.
>
> Either way a floor is worth having — it stops a stray `S1000` in someone else's
> g-code from bogging the spindle down mid-cut. Set it in the VFD and grblHAL
> inherits it; `100` Hz (6 000 RPM here) suits general work, and going lower is
> reasonable only if you actually run large-diameter cutters.

### Communication block

| Register | Meaning |
|---|---|
| `PD001` | run command source → RS-485 |
| `PD002` | frequency source → RS-485 |
| `PD163` | slave address (match `$476`) |
| `PD164` | baud rate |
| `PD165` | data format (8N1, RTU) |

The numeric codes for `PD164`/`PD165` differ between Huanyang revisions and even
between manuals for the same model. **If you already run a working Huanyang on this
bus, read its values off the panel and copy them** — a proven set beats a table.
Otherwise follow the manual that came with your unit.

---

## 5. Commissioning order

Do it in this order; each step is checkable on its own.

1. **Power off.** Wire A/B/GND. Leave the spindle unmounted or the collet empty.
2. Program the VFD: motor block → frequency block → communication block last.
   (Communication last, so you are not fighting a half-configured drive over a bus.)
3. Set `$395` to the matching driver, then **reset the board**. `$476` (the VFD's
   Modbus address) becomes visible only after that reset — set it then, unless the
   VFD is already on the default address `1`.
4. Send `$I` — the driver must be listed. No entry means `$395` did not take, or the
   board was not reset.
5. Send **`$SPINDLESH`** and read the trailing `rpm_min,rpm_max` field of the active
   spindle. If it reflects your spindle, the controller is talking to the VFD and
   reading its registers — that is the moment the bus is proven.

   > Do **not** look for this in `$$`. `$30`/`$31` are the PWM spindle's own settings
   > and stay whatever you typed; a VFD's range lands in the spindle HAL
   > (`grbl/spindle_control.c`), which only `$SPINDLESH` reports.

6. Command a low speed (e.g. `M3 S6000`), watch the reported RPM settle at the
   commanded value, then `M5`. Only then fit a tool.
7. Set **`$340`** (spindle at-speed tolerance) to about `5` percent.

   > ### ⚠️ Why `$340=0` breaks the first cut
   > A Modbus VFD reports its real speed back, so grblHAL can wait for the spindle to
   > actually reach the commanded RPM before running the next block. That wait is
   > enabled **only** when `$340 > 0` (`spindle_control.c`: `at_speed_enabled =
   > at_speed_tolerance > 0.0f`). Left at the default `0`, `M3 S24000` returns
   > immediately and the machine starts cutting while the spindle is still spinning
   > up — which a VFD spindle can take several seconds to finish.
   >
   > `$394` (spindle on delay) solves the same problem with a fixed wait, but it waits
   > the same amount whether the spindle needs it or not. With a VFD, `$340` is the
   > better tool: it waits exactly as long as the drive says it needs.

### Doing steps 2-7 with no motor connected

Recommended, in fact — settle the parameters and the bus while nothing can spin.

Everything above works with the VFD's **U/V/W empty**: parameters are set from the
panel, and the RPM range grblHAL reads comes from the drive's own registers, not from
the motor. Even a brief `M3 S6000` is meaningful — the RPM the sender displays is the
drive's output frequency, so the whole command path is proven. Only the current
reading stays at zero.

Two things to respect:

- **Insulate the U/V/W leads** if they are already in the terminals. They carry full
  output voltage the moment the drive runs.
- **Before wiring the motor afterwards: kill mains and wait for the DC bus to
  discharge.** The bus capacitors hold a dangerous voltage after the drive is
  switched off — wait for the display to go dark, then several minutes more (if the
  unit has a DC-bus LED, wait for it to go out). This applies every time the spindle
  is rewired, not just during commissioning.

Some drives detect **output phase loss** and fault when run with no motor. On the
cheap V/f Huanyang units this is usually absent, but if a `PHL`/`OPL`-type code
appears, it is expected behaviour — skip the spin test and connect the motor.

If the panel refuses to accept a parameter edit, the drive's parameter lock is set;
check which register that is in the manual for your revision.

---

## 6. Troubleshooting

| Symptom | Cause worth checking first |
|---|---|
| `ALARM:19` (Modbus exception) | wiring: A/B swapped, no shared GND, VFD not powered; then address / baud mismatch |
| Spindle always runs at max | `PD144` (see the trap above) |
| Reported RPM is a fixed multiple of the commanded one | `PD144` again — the ratio tells you the factor |
| Driver not listed in `$I` | `$395` not set, or the board was not reset afterwards |
| Works, then drops out under load | ground/shielding: route the RS-485 pair away from motor cables, terminate 120 Ω |
| `M3` turns the spindle the wrong way | swap any two motor phases (see below) |
| Spindle will not go below some RPM | that is `PD011`, working as intended |

**Bus timing note:** Huanyang drives have been measured failing to answer when the
silent period between messages is under 6 ms. The firmware already applies longer
silence timeouts per baud rate for this family, so a Huanyang that does not respond
is a wiring or parameter problem, not a timing one.

### Spindle turns the wrong way

Swap **any two of the three motor phases** at the drive's `U`/`V`/`W` terminals; the
third stays put. That is the whole fix — a three-phase motor reverses on any swapped
pair. Then re-check that `M3` is clockwise seen from above and `M4` counter-clockwise.

There is no setting for this on a Modbus spindle. `$16` ("invert spindle signals")
acts on the **PWM** spindle's output pins (`settings.pwm_spindle.invert`), while a VFD
driver sends direction as a command on the bus — the Huanyang driver writes `0x11` for
CCW and `0x01` for CW, and nothing inverts it.

> Power down, wait for the display to go dark **and several minutes more**, and measure
> the DC bus at `P/+` and `N/−` before opening the terminal cover. See §5.

---

## 7. Safety

- **E-stop must cut the spindle in hardware.** A Modbus stop is a message; a message
  can be lost. The E-stop chain has to drop the VFD's own enable or its supply, not
  rely on the bus. This is not a redundancy nicety — it is the only stop that works
  when the software is the thing that failed.
- **Direction changes only at standstill.** Reversing a 24 000 RPM spindle through
  zero stresses bearings and the drive; command `M5`, let it coast down, then start
  the other way.
- The spindle's own cooling (air or water) must be running before you cut. A Modbus
  link tells you the VFD is happy, not that the water pump is.

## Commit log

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2026-06-06 Translate Schematic_References + VFD wiring; move v2 Architecture to private
    - Docs/Schematic_References.md: full English translation (TPS5430, AMS1117,
    74HC14D, W5500, SP3485, spindle 0-10V sections)
    - Docs/VFD_Wiring_Guide.md: minor fixes (support email/links updated)
    - Docs/v2_Architecture.md: removed from public repo, moved to .private/
    (R&D planning document, kept locally for internal use)
    - .gitignore: add .private/ to keep internal planning out of git
2026-06-06 Fix D1-D6 naming confusion: LED1-LED6 (KT-0805G) vs D1 (SS54 diode)
    The BOM uses separate designators:
    - LED1-LED6 = KT-0805G status LEDs (24V/5V/3V3/ISO/USB/VFD indicators)
    - D1 = SS54 Schottky (reverse polarity protection on 24V input)
    - D2-D6 = other diodes (SS34, PSM712, 1N4742A)
    Documentation now correctly uses LED1-LED5 for status LEDs,
    and clarifies D1=SS54 as the reverse polarity Schottky.
    Files:
    - Docs/First_Power_On_Procedure.md: LED table updated, troubleshooting,
    checklist, bring-up log template all use LED1-LED6
    - Docs/Quick_Start_Guide.md: visual inspection now mentions KT-0805G
    Hardware/BOM verified: SS54 reverse polarity protection IS on the ordered board.
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2026-06-09 Add SECURITY and CODE_OF_CONDUCT; refresh CONTRIBUTING
    - SECURITY.md: how to report hardware safety, firmware vulnerabilities,
    and configurator issues responsibly. Covers scope, expected response
    time, and what's out of scope (upstream grblHAL, third-party gear).
    - CODE_OF_CONDUCT.md: short, focused rules for a small solo-founder
    project. Be respectful, stay on topic, no harassment. Reports go
    to hello@rectabot.org.
    - CONTRIBUTING.md: refresh references — RectaPad replaces the old
    RectaBot-pendant name; configurator is now at Docs/configurator/;
    hardware files are tracked under CERN-OHL-S (no longer 'future').
    Clarified the licensing breakdown for contributions across the r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
2026-07-21 docs: pinout, power-tree & wiring corrections from bench bring-up (#1)
    Documentation corrections validated during v1 hardware bring-up:
    - Stepper invert masks: $2=0 / $3=0 (not 31) — 74HC14D inverter already
    accounted for in common-anode mode; $4 (enable invert) TBD until ENA wired.
    - D1/SS54 role: +5V ORing Schottky (blocks USB-C back-feed), NOT 24V
    reverse-polarity protection — v1 has none (planned v2). Fixed
    First_Power_On_Procedure, Product_Specification, README power tree.
    - CN40 pins: VAC/MIST un-swapped to match silk (GP0=VAC, GP1=FLOOD,
    GP2=MIST); GP42 = grblHAL safety door input.
    - Input wiring guide: sinking/active-LOW inputs (mechanical, NPN sensor;
    PNP needs relay)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
    [CPL_RectaBot_V1.0.csv]
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2026-07-21 chore: pre-publish tidy — accurate status, board render, honest wording
    - README: status -> "v1.0, first 5 boards assembled & bench-tested (RS-422
    pendant pending)"; remove false "24V reverse-polarity protection" claim;
    drop RectaPad repo link (not yet public); add annotated board render (hero).
    - First_Power_On: generalize the power-on log (drop internal "5 boards").
    - CONTRIBUTING/NOTICE: neutral wording (prototype/power-on) over "bring-up".
    - gitignore the separate website/ staging (rectabot.github.io).
2026-07-22 docs: real board hero + as-shipped photo, 5th mount hole, key differentiators
    - Hero image now the assembled board photo; KiCad render moved to Hardware
    section as a labeled silkscreen/layout reference
    - Add "how the board arrives from JLCPCB" photo to Hand_Solder_Components
    (SMT pre-assembled, 28 TH parts hand-soldered)
    - Mechanical spec: correct mounting holes 4 -> 5 (central diagonal support
    hole, 3.5mm drill / 7.5mm annular pad)
    - README features: single-board integration (soldered, not socketed; EMI-aware
    layout), discrete W5500 to WIZnet reference design (not a module), ORing
    Schottky power/USB coexistence (no VBUS/5V jumpers)
    - .gitignore: publish only curated board-photo.we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
2026-07-22 docs(configurator): rebuild as firmware selector (kinematics -> UF2)
    Repurpose the configurator from a grblHAL $-settings generator into a
    firmware-variant picker: choose axes (3/4/5) + dual-Y gantry
    (none/ganged/auto-square) and it resolves to one of the 7 kinematic
    variants, shows the matching .uf2, download link and flash steps.
    - Runtime tuning (steps/mm, speeds, travel, limits, VFD choice) is handed
    off to RectaControl; "fully-loaded firmware" note explains every build
    ships the full VFD/laser/I-O set, selected at runtime
    - Custom kinematics (dual-X/Z, non-square, exotic) -> mailto flash-to-order
    - Drop the old 5-step $ generator and WebSerial flashing (not for UF2)
    Co-Authored-By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
2026-07-23 docs(configurator): enable 4axis-a-autosquare-y (now built)
    The 7th kinematics variant is built and verified, so flip it from
    built:false to built:true — removes the "coming soon" badge and points
    the download at the real firmware .uf2.
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2026-07-23 docs: sync settings + connector assignments to the validated board
    Pre-publish consistency audit against the board map, silkscreen, and the
    reference board's $$ dump. Fixes:
    Settings (were $2=31/$3=31/$4=1 everywhere — wrong for a Common Anode board):
    - $2=0 (step invert OFF), $4 = enable invert on all axes (7/15/31 for 3/4/5-axis),
    $5=0, $6=1. Direction ($3) documented as per-machine, not a fixed value.
    - Files: Quick_Start_Guide, Hardware_Design_Guidelines, Product_Specification,
    Schematic_References, Pinout.md.
    Connectors:
    - CN34 stepper: pin order is +5V/STEP/DIR/EN (common anode), not STEP/DIR/EN/GND.
    - CN22 = DOOR, CN32 = RS-485 Modbus (Hand_Solder had them swapped).
    - CN41 = R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
2026-07-23 chore(website): bring the site into the repo, deploy via Pages Action
    The marketing site was a separate, local-only git repo ignored by this project.
    Fold it in as a tracked website/ folder (it's public content — no reason to keep
    it out) and deploy it to GitHub Pages from that folder via a GitHub Actions
    workflow. The site's CNAME (rectabot.org) carries the custom domain.
    - Un-ignore website/ in .gitignore
    - Remove the nested website/.git (full history preserved as a bundle in
    .private/web-backup/, which stays untracked)
    - Add .github/workflows/deploy-pages.yml (publishes website/ on push to main)
    At go-live: flip the repo public and set Pages source to "GitHub Actions" — no
    separat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
2026-07-23 docs(website): update README to reflect in-repo Pages deployment
    No longer a separate rectabot.github.io repo — the site lives in this repo's
    website/ folder and deploys via the Pages Action.
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2026-07-24 fix(docs): replace dead datasheet links (W5500, SP3485)
    The W5500 link 404'd and the SP3485 link redirected to MaxLinear's news
    hub. Point W5500 at the current PDF (WIZnet v110e) and SP3485 at its
    product page (maxlinear.com/SP3485, opens in-browser). TPS5430, AMS1117
    and 74HC14 links verified live.
2026-07-24 docs: remove unreleased-product refs, dead placeholders, and v2 promises
    Pre-publish scan cleanup:
    - Drop RectaPad references and links to its private repo (404 for the
    public + teases an unreleased product): CONTRIBUTING, SECURITY, spec.
    - Fix the spec's Support section: real rectabot.org contacts, drop the
    (TBD) GitHub/docs/Discord placeholders and the wrong .com email domain.
    - Replace "planned for v2" promises with plain statements of the v1
    limitation (input-side isolation only, no reverse-polarity protection)
    across README, website, and the spec/first-power-on docs.
2026-07-24 fix(configurator): point firmware .uf2 downloads at the master branch
    The firmware repo's default branch is master, not main — the download
    links used /raw/main/ and would 404 for every variant once public.
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2026-07-27 docs(vfd): add the RS-485 / Modbus spindle guide
    The existing VFD guide covers analog control only (0-10V on CN39), while the
    shipped firmware carries every VFD protocol compiled in — so the digital path,
    which is the better one where the drive supports it, was undocumented.
    Written against the driver source rather than from the VFD manual, because the
    surprising part is on our side: with the Huanyang v1 protocol grblHAL reads the
    speed range OUT of the drive (PD144, PD005, PD011, PD142). A PD144 left at its
    factory value silently makes every commanded RPM wrong and pins the spindle at
    maximum — called out as its own warning, since the sender looks guilty.
    Includes wiring, driver selec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
2026-07-27 docs(vfd): list the spindle driver ids, and how to ask the board for them
    $395 takes a number, and guessing it is the first place a Modbus setup stalls.
    $SPINDLESH enumerates what the firmware really carries, so the guide points at
    that first and gives the shipped build's ids as a convenience — read off a live
    board rather than copied from a header that may drift.
2026-07-27 docs(pinout): correct the limit wiring — NC with $5=0, and say why
    The guide paired "mechanical switch (NO contact)" with $5=0 elsewhere in the
    same file. Those two together put the machine in alarm at power-up: with $5=0 an
    input reads triggered when the circuit is OPEN, which is the resting state of a
    NO switch. Verified on the reference machine, where NC switches on GND–SIG with
    $5=0 behave correctly and a disconnected wire shows as a tripped limit.
    Rewritten as the choice it actually is: NC is what to ship, because a cut wire,
    a loose terminal or a corroded contact then look like a tripped limit and stop
    the machine, while a NO switch fails silent. Adds the matching sensor suffixes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
2026-07-28 docs(vfd): correct the guide against a live commissioning run
    Six fixes, each found by actually bringing a Huanyang HY03D023B up on the
    board rather than by reading the source:
    - the Modbus address is $476, not $460. Our firmware compiles in every VFD
    protocol (N_SPINDLE=8), which puts grblHAL in its multi-spindle branch and
    leaves $460 registered but hidden. Confirmed by $ES on the running board,
    which lists 476 and no 460. Also notes that it only appears once $395 names
    a VFD driver and the board is reset.
    - read the RPM range with $SPINDLESH, not $$. $30/$31 belong to the PWM
    spindle and never move; a VFD's range lands in the spindle HAL.
    - new step 7: set $340. With the defaul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
2026-07-28 docs(vfd): say how to reverse a Modbus spindle, and why no setting does it
    Filip's spindle came up with M3 turning counter-clockwise. The reflex is to
    look for an invert setting, and $16 looks like the one — but it acts on the
    PWM spindle's output pins, while a VFD driver sends direction as a bus command
    (the Huanyang driver writes 0x11 / 0x01, uninverted). The fix is two swapped
    motor phases, with the same DC-bus warning that applies to any work behind
    that terminal cover.
2026-07-29 docs(power-on): the board comes up at a fixed address, not on DHCP
    The Ethernet check told people to ping whatever address their router handed
    out. RectaBot firmware has never been meant to work that way, and from the
    2026-07-29 builds it genuinely does not: 192.168.5.1, hostname rectabot,
    static. Someone following this step would wait for a lease that never comes
    and conclude the W5500 was dead.
    Says what to do instead — put the PC on the same subnet, no router needed,
    a direct cable is fine — and what it means if the board answers nowhere.
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2026-08-03 docs(site): put the sender on the site, and fix the licence it claims
    The landing page was written before RectaControl joined the first release, so
    the one thing an operator actually looks at every day was missing from it: no
    section, no screenshot, no link, and the comparison table quietly implied the
    software question was unanswered. Adds a Software section with the screenshot,
    a control-software row, nav and footer links, and lists the sender in the repo
    README next to the firmware.
    Two corrections while in there. The firmware was described as MIT in two places
    - it is a grblHAL fork and inherits GPL-3.0, as LICENSE and NOTICE already say.
    And the comparison table said the pendant was in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
2026-08-03 docs(quick-start): describe the parcels the reader gets, not the ones we got
    The unboxing list was our own first batch written down: five boards, twenty-eight parts times five sets, and the couriers that happened to carry them. A person following this guide has ordered their own quantity from their own supplier, and reading that they should find five boards in the box is simply wrong for them. Same information, written from their side - plus the line that was missing, which is what to skip if they bought a board already assembled.
2026-08-04 fix(pcb): lift the TPS5430 enable pin off the 24 V rail
    The Gerbers here were the 4 June export, the same set the first boards were
    made from, and they carry that batch's defect: U1 pin 5 (ENA) sat on 24V_IN,
    the same net as VIN. Those boards run only because the pin was lifted by hand
    afterwards. Anyone ordering from these files would have reproduced the fault
    and had no way to know it was there.
    Re-exported with the via removed, so ENA now floats and the files describe a
    board that powers up as drawn.
    Verified against the netlist rather than by eye: of the connectivity groups in
    FlyingProbeTesting.json exactly one differs, U1_5 leaving 24V_IN to sit alone.
    The 280 named components are un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
    [Drill_NPTH_Through.DRL, Drill_PTH_Through.DRL, Drill_PTH_Through_Via.DRL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]
2026-08-04 docs(configurator): describe the tool that exists, and keep one copy of it
    The site was still advertising the configurator it replaced in July. It promised
    a five-step wizard producing a complete grblHAL configuration, downloadable as
    config.txt, with steps/mm calculated from motor and screw specs, VFD choices and
    machine presets - beside a sample of generated $$ output. The tool that actually
    ships asks two questions and hands over a .uf2. None of those five claims had
    anything behind them, and the settings work they described lives in RectaControl
    now. Rewritten to say what it does, including why picking right matters: an image
    built for another layout resets the board, and one without gan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
2026-08-04 fix(site): the waitlist button failed silently on machines with no mail app
    "Join the waitlist" was a bare mailto: link. On a computer with no default mail
    client registered - which is most Windows machines whose owner reads mail in a
    browser - clicking it does nothing whatsoever. No error, no new window, no hint
    that the address exists. That is the one button on the site meant to bring in
    buyers, and it was quietly dropping an unknown share of them.
    The address is now reachable without a mail app: a copy button beside the
    original link, with plain text underneath explaining what happened if the first
    button appears dead. Copy falls back to a hidden textarea where the clipboard
    API is unava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
2026-08-04 fix(site): the coolant outputs are not isolated, and drivers are not included
    Three claims in the integration section were wrong, all flagged by Filip reading
    the live page.
    "The board already drives them from isolated outputs" - it does not. VAC, FLOOD
    and MIST leave GP0-GP2 through spare 74HC14D channels and share the board's
    ground. The optocouplers and the 24V_ISO rail are on the input side, as the rest
    of this page says correctly in six other places, including a line that spells
    out "v1 isolates the input side only". This bullet was the last survivor of
    wording the block diagram was corrected for months ago.
    The 74HC14D is a Schmitt-trigger inverter, not a buffer, so the coolant signa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
2026-08-04 docs(aux): say which way round an SSR goes on CN40
    CN40 carries a +5V pin for a reason, and nothing in the documentation said what
    it was for. Common-anode wiring is explained five times over for the stepper
    drivers and not once for the coolant outputs, which use the same topology
    through the same inverter. Quick_Start_Guide did not mention coolant at all, so
    someone following it from unboxing to first cut never learns the connector
    exists.
    Getting it wrong is quiet and expensive. The 74HC14D inverts, so each coolant
    pin idles at ~5 V and is pulled to 0 V when the M-code asserts the output.
    Wire the SSR between the signal pin and GND - the intuitive way, and the way
    you would wire almost an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
2026-08-04 docs(aux): say which relays these outputs can drive, because most cannot
    The coolant pins were described as "SSR outputs" everywhere, which reads as an
    invitation to buy the SSR everyone buys. A Fotek SSR-40 DA does not work on
    them, and nothing said so.
    Measured on the reference board: with the Fotek wired common-anode across +5V
    and MIST, the pin sits at 3.11 V instead of falling to ~0 V, leaving 1.96 V
    across the relay input against the 3 V its datasheet demands, while already
    drawing about 6 mA through a channel rated for 4 mA. It never triggers, and no
    rewiring changes that.
    The cause is not a fault. Each pin is a 74HC14D channel behind 330 R - R45, R63
    and R91, the same value and top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
2026-08-04 docs(aux): give one number to buy by, and explain why a module works
    The previous pass said which relays fail. It did not say what to look for on a
    product page, so the reader was left to work it out from the electrical
    description. Now the rule is a single figure they can check before ordering:
    input current at 5 V must be 5 mA or under.
    Added the reason underneath, because it is what makes the rule memorable. A
    relay module has a gain stage - this board's ~3 mA lights an optocoupler, whose
    transistor then pulls the 70-80 mA of coil current out of the module's own VCC.
    A solid-state relay wired directly has no such stage and has to be switched by
    whatever current the pin can push. That is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
2026-08-04 docs(aux): finish the sweep - the README still had the sentence word for word
    Two passes today rewrote the coolant outputs on the site and in the reference
    docs, and the README kept the original claim untouched: "The only external
    hardware you add is 2-3 SSRs for coolant/vacuum - the board already drives them
    from isolated outputs." Both halves are wrong, and it is the first paragraph a
    person reads on the repository.
    This is the fifth time today the same shape of mistake has turned up: a
    correction lands where someone pointed, and the same claim survives somewhere
    else. Searched every markdown and html file for SSR and relay rather than
    working from memory, which is what should have happen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
2026-08-04 fix(aux): the Fotek does work - retract a number that was never measured
    Filip wired a Fotek SSR-40 DA to MIST with a 230 V lamp as the load. It
    switches. The documentation added earlier today said it could not, and said so
    under the word "measured", which it was not.
    What happened: he was asked to probe across the relay's control terminals rather
    than to ground, and reported 3.11 V. That figure was then read as though it were
    a pin-to-ground reading, subtracted from the 5.07 V open-circuit value, and
    written up as "only 1.96 V reaches the relay". The subtraction assumed where the
    probe was. The 3.11 V was the answer already - above the Fotek's 3 V minimum,
    which the same paragraph had itse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
2026-08-04 fix(aux): 4 mA is a test point, not a limit - stop warning about it
    Filip: the inverter is rated 25 mA per pin. Correct, and the previous wording
    confused two different datasheet figures. 4 mA is where the 74HC14D guarantees
    VOL - a DC characteristics test condition - while 25 mA per pin is the absolute
    maximum. Drawing 5.9 mA is not running the part over its rating; it only means
    the datasheet stops promising a specific VOL.
    The measurement already showed this and it was misread. Around the loop,
    5.07 V = 3.11 V across the relay + 1.96 V across the 330 R, which leaves VOL at
    about 0 V. The output was pulling to ground perfectly well at 5.9 mA, with
    roughly four times the headroom left to 2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
2026-08-04 docs(pendant): the site promised handheld control the firmware cannot do
    Final accuracy pass over the site and docs, checking what is advertised against
    what my_machine.h actually compiles.
    The pendant header was the one that failed. MPG_ENABLE and KEYPAD_ENABLE are
    both commented out in the shipped firmware, so CN41 is copper and transceivers
    and nothing else - yet the site said "Pendant-ready: for handheld control
    without a computer", offered it again in the SD card section, and the
    configurator listed "the RS-422 pendant" among the things every build contains
    and you pick at runtime. Someone could buy the board to drive a machine from a
    handheld unit.
    The repository documentation was al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
2026-08-04 docs(readme): coolant takes a solid-state relay too, not only a module
    The rest of the documentation was brought in line when the Fotek turned out to
    work; the README was not, and still told a reader that coolant "needs
    optocoupler-input relay modules" - which rules out the SSR that has since been
    wired to CN40 and run from M7. It also carried the ~4 mA figure that was later
    corrected, where the honest numbers are 330 R in series and 25 mA per pin.
    Both lines now say what the other four places say. Checked by searching for
    Fotek across every markdown and html file rather than trusting memory of what
    had already been edited - which is how this one was missed the first time.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
2026-08-05 feat(brand): every mark draws the same letter, and one corner that matches it
    The assets had drifted apart. The app icon drew the letter a quarter larger
    than the SVGs did, so each file's corner radius had been chosen against a
    different letter — 12.5% here, 16.1% there — and the inner frame survived in
    rectabot-icon-cyan.svg alone.
    They are now one drawing. Measured against the app icon master, rendered
    through Chromium at 1024 and fitted over 126 points: the letter starts at
    283,201 against the master's 282,201 and its elbow is a 165 px arc against
    165. Corner radius follows the letter at 16.1% of the edge everywhere,
    which is why the rects became paths — rx rounds all four corners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
2026-08-06 docs: four connector references named the wrong connector
    Found while tracing the step signal to compare it against another RP2350B
    board. Every claim below was checked against the fabrication netlist
    (Gerber_RectaBot_1.0/FlyingProbeTesting.json), which is the authority.
    CN34-CN38 are +5V / STEP / DIR / EN. There is no GND pin on a stepper
    connector and there cannot be one: common anode means pin 1 feeds the
    driver's PUL+/DIR+/ENA+ and the 74HC14D pulls the minus leads down, so the
    signal lines are the return path. Three files said "STEP, DIR, EN, GND":
    - Product_Specification_v1.0.md listed it for all five axes, while the same
    row said "5V Common Anode" - a combination that cannot exist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
